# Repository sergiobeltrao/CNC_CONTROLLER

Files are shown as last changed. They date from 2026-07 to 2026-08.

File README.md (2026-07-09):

# CNC PSU and Driver Board

Project under development...

CNC PSU and Driver Board. Hardware design of a modular CNC controller integrating a 400W LLC power supply with stepper and DC motor drivers.

## Main Features
- Universal AC input: 85 VAC to 265 VAC
- 400W LLC resonant power supply
- Active Power Factor Correction (PFC)
- Stepper motor drivers
- DC motor drivers
- Microcontroller
- Compatible with grblHAL firmware

## Main Components
- **PFC Controller:** [L4986A](https://www.st.com/en/power-management/l4986.html)

- **Auxiliary Power Supply:** [VIPER222L](https://www.st.com/en/power-management/viper222.html)

- **Microcontroller:** [STM32F411CEU6](https://www.st.com/en/microcontrollers-microprocessors/stm32f411ce.html)

- **Stepper Motor Driver:** [STSPIN820](https://www.st.com/en/motor-drivers/stspin820.html)

- **DC Motor Driver:** [STSPIN840](https://www.st.com/en/motor-drivers/stspin840.html)

## Development Tools
- **PCB Design:** Altium Designer
- **Firmware:** [grblHAL](https://github.com/grblHAL/STM32F4xx)

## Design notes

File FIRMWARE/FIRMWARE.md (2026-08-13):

# Flashing the Firmware

The board can be programmed using either:

- **ST-LINK**
- **UART (STM32 Bootloader)**

The firmware source code is available in the official **grblHAL** repository for STM32F411:

https://github.com/grblHAL/STM32F4xx

For convenience, this repository also includes a **precompiled binary** in this directory, ready to be flashed to the board.

## ST-LINK Programming

1. Download and install **STM32CubeProgrammer** from the STMicroelectronics website:

   https://www.st.com/en/development-tools/stm32cubeprog.html

2. Connect the following signals to connector **P201**:
   - **SWDIO**
   - **SWCLK**
   - **GND**
   - **3.3V**

3. Open **STM32CubeProgrammer**, select **ST-LINK** as the connection interface, configure the connection parameters as shown below, and click **Connect**.

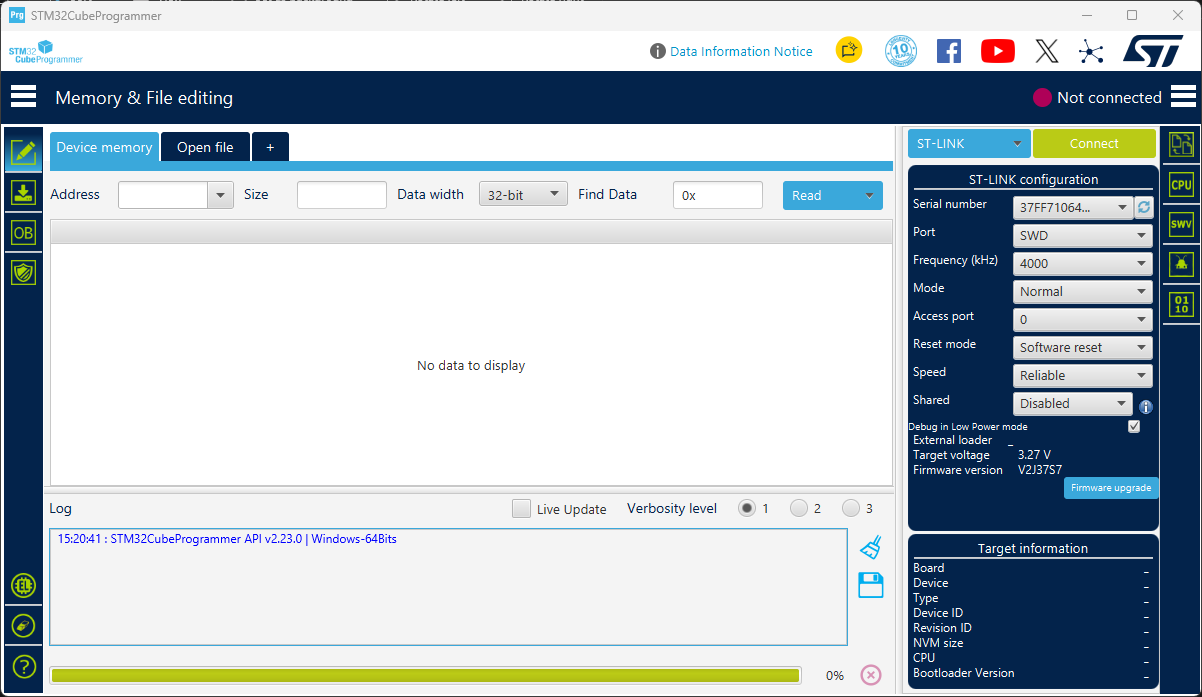
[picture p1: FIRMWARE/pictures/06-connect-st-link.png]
   

4. If the connection is successful, the microcontroller information will be displayed in the lower-right corner of the window.

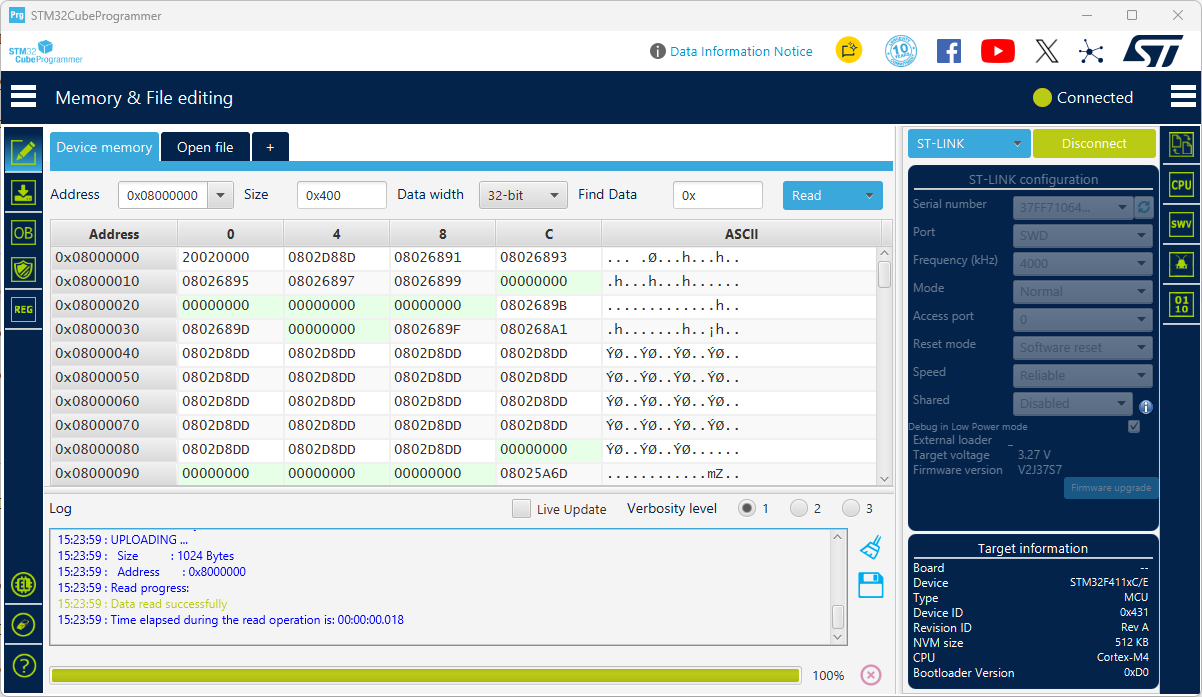
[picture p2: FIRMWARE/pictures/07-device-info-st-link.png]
   

5. In the left panel, select **Erasing & Programming**. Then select the firmware **.bin** file and click **Start Programming**.

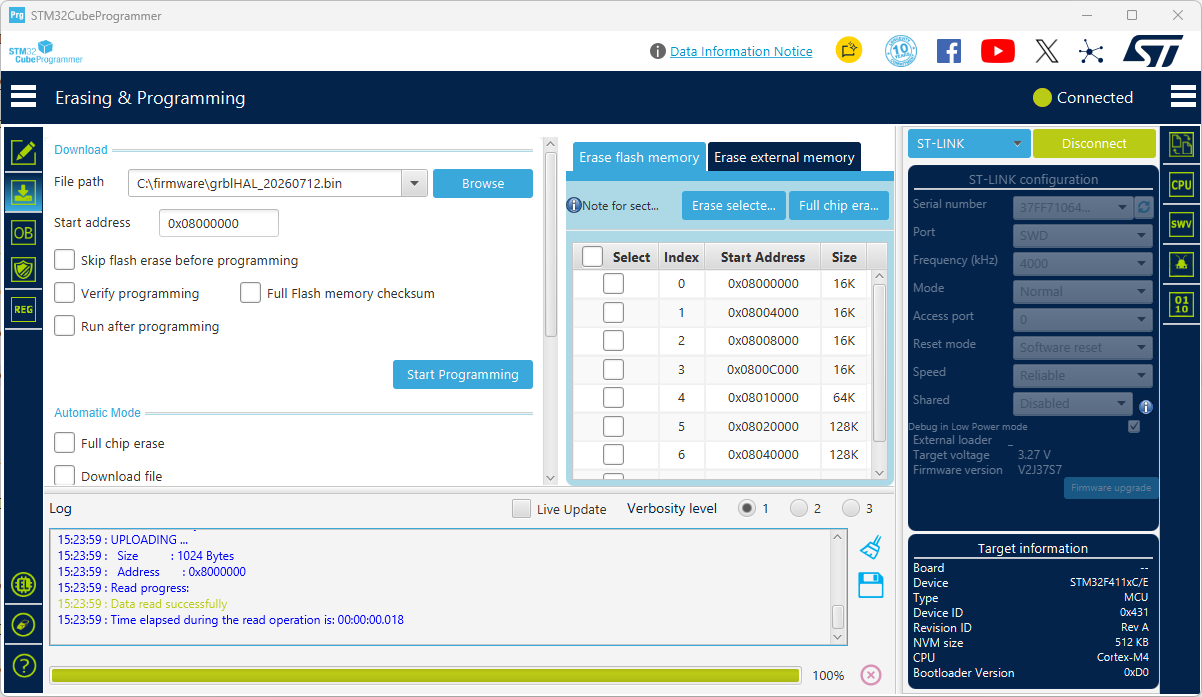
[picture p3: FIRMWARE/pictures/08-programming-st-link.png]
Preparing to program
   

6. Wait for the programming process to complete. When the **"File download complete"** message appears, the firmware has been successfully programmed.

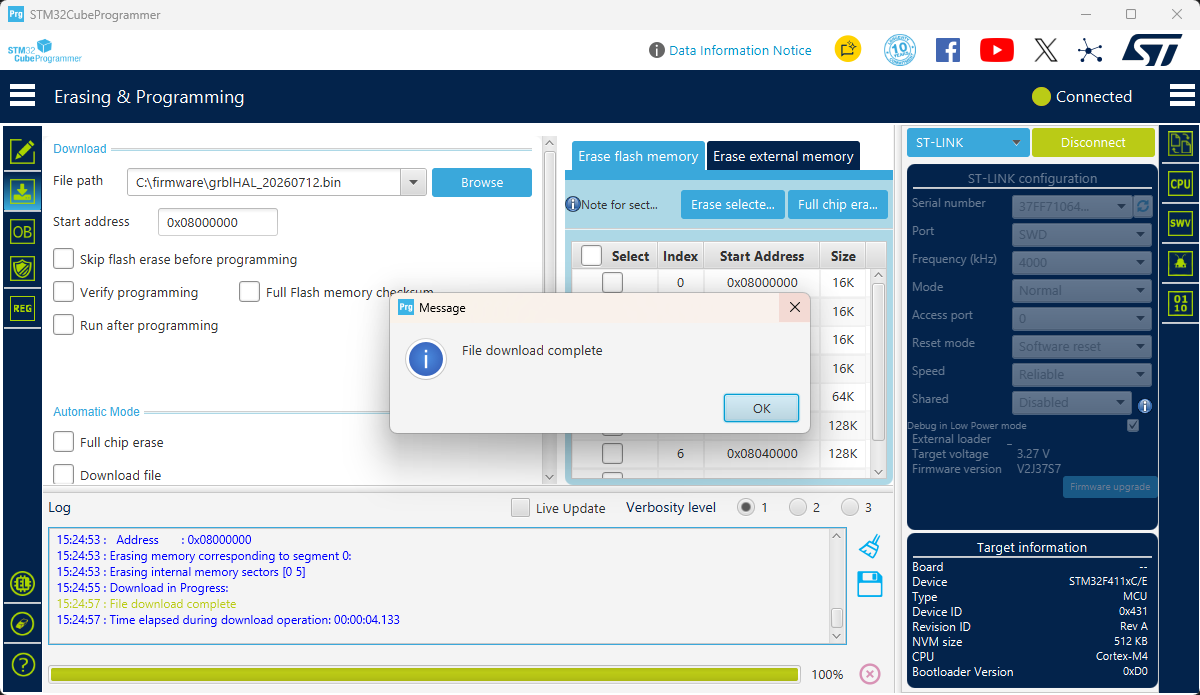
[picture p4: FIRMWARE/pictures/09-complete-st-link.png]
   

You can now disconnect the ST-LINK programmer and reset or power cycle the board to start the new firmware.

## UART Programming (Bootloader Mode)

1. Download and install **STM32CubeProgrammer** from the STMicroelectronics website:

   https://www.st.com/en/development-tools/stm32cubeprog.html

2. Connect the following signals to connector **P200**:
   - **TX**
   - **RX**
   - **VCC**
   - **GND**

3. Put the microcontroller into **Bootloader Mode**:
   1. Press and hold the **NRST** button.
   2. Press and hold the **BOOT** button.
   3. Release the **NRST** button.
   4. Release the **BOOT** button.

4. Open **STM32CubeProgrammer**, configure the connection as shown below, and click **Connect**.

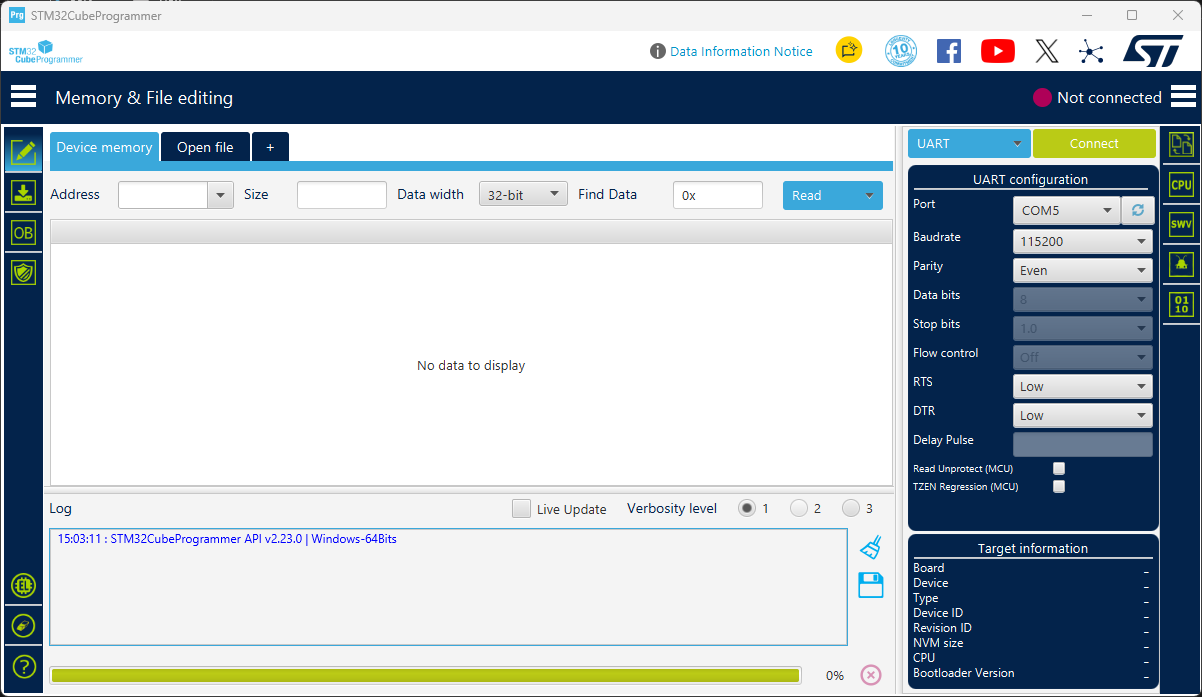
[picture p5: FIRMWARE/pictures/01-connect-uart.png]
   

5. If the connection is successful, the microcontroller information will be displayed in the lower-right corner of the window.

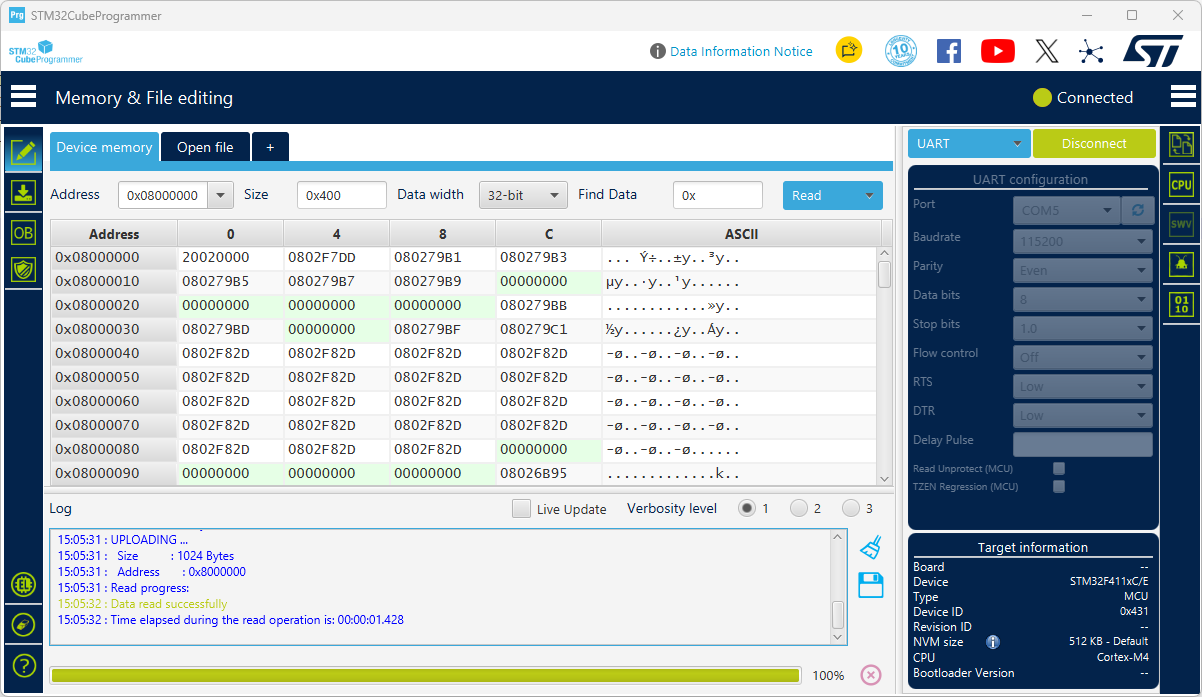
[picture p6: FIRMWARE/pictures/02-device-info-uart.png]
   

6. In the left panel, select the **Erasing & Programming** tab. Browse for the firmware **.bin** file and click **Start Programming**.

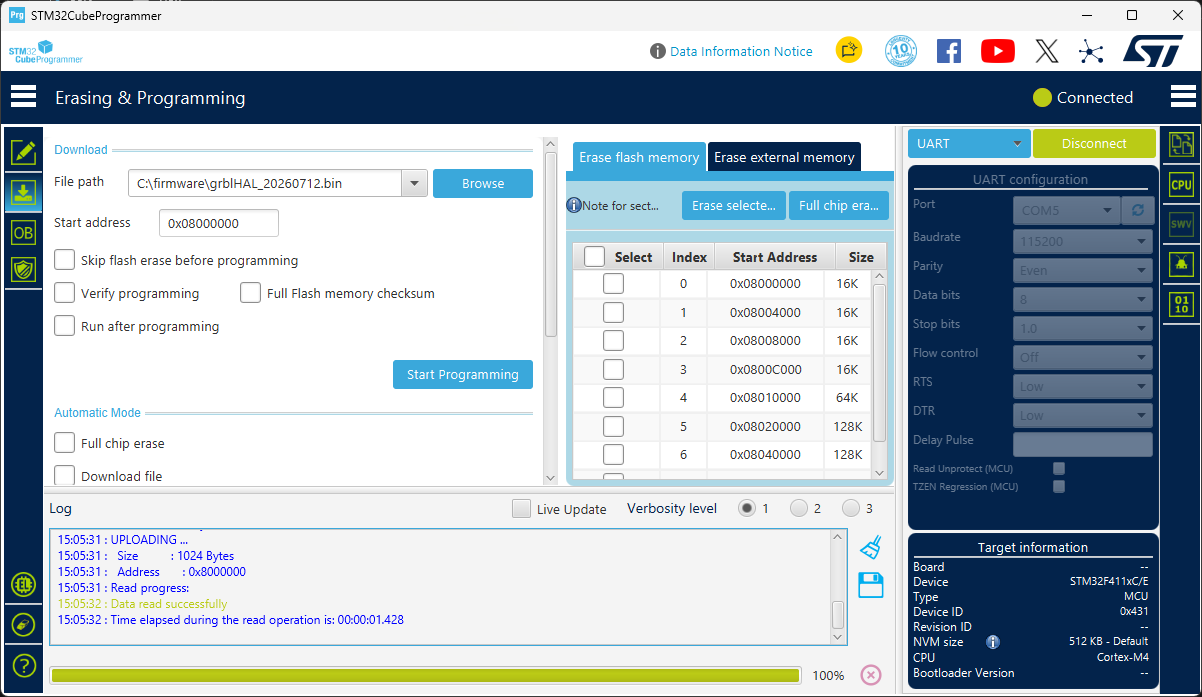
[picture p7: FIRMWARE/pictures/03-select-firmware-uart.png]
   

7. Wait for the programming process to complete.

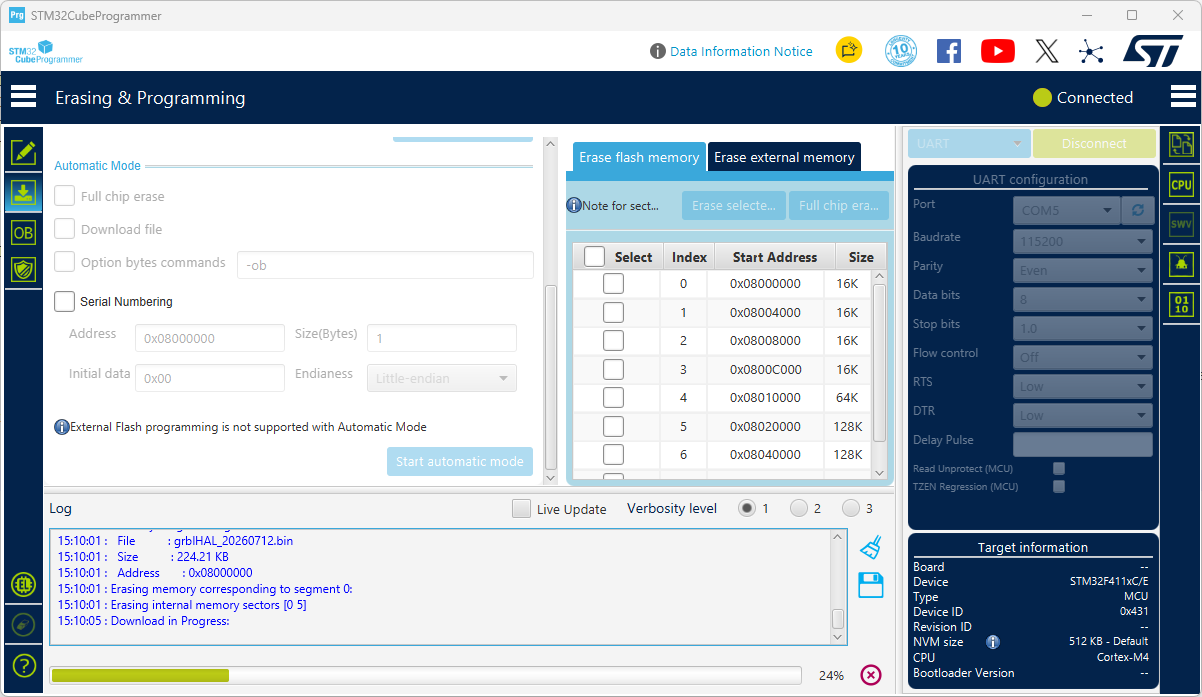
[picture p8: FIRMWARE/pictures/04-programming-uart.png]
Programming in progress
   

8. When the message **"File download complete"** appears, the firmware has been successfully programmed.

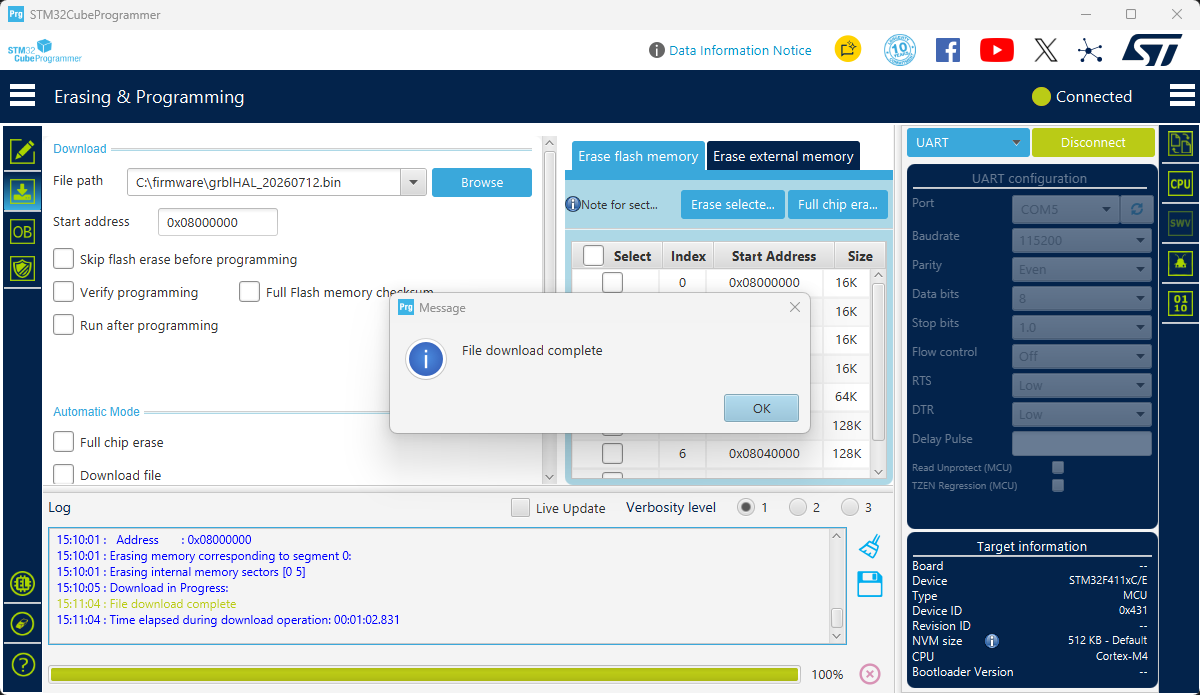
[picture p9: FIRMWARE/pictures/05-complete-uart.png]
   

You can now disconnect the board from **STM32CubeProgrammer** and reset or power-cycle the microcontroller to start the new firmware.

# grblHAL Configuration

After flashing the firmware, configure the following parameters:

| Parameter | Value | Description |
|---|:-----:|---|
| `$5` | `0` | Sets the limit switches as **active-high**. |
| `$21` | `1` | Enables the physical limit switches. When triggered, grblHAL enters the alarm state and immediately stops all motion. |
| `$6` | `0` | Sets the **probe** input as **active-high**. |

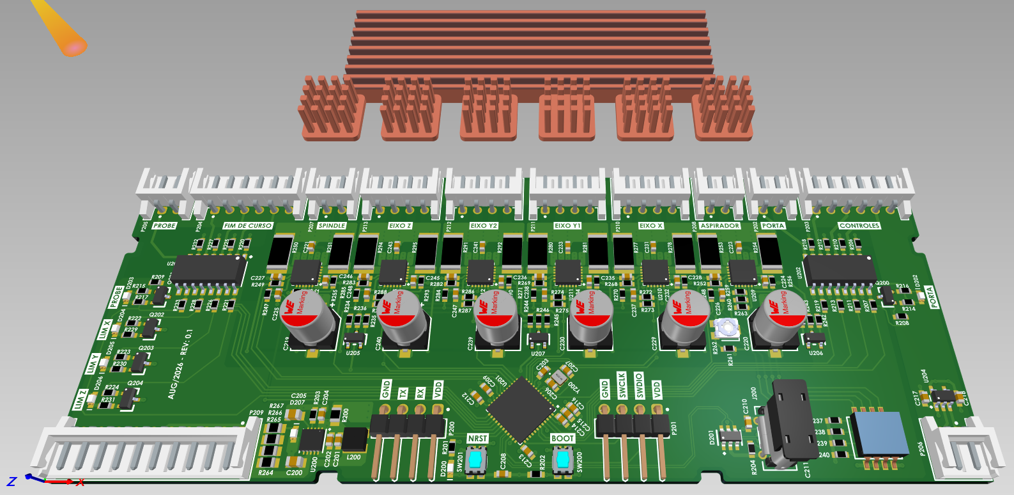
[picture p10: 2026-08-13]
PRODUCTION_FILES/REV_0_1/DRIVER_REV_0_1.png

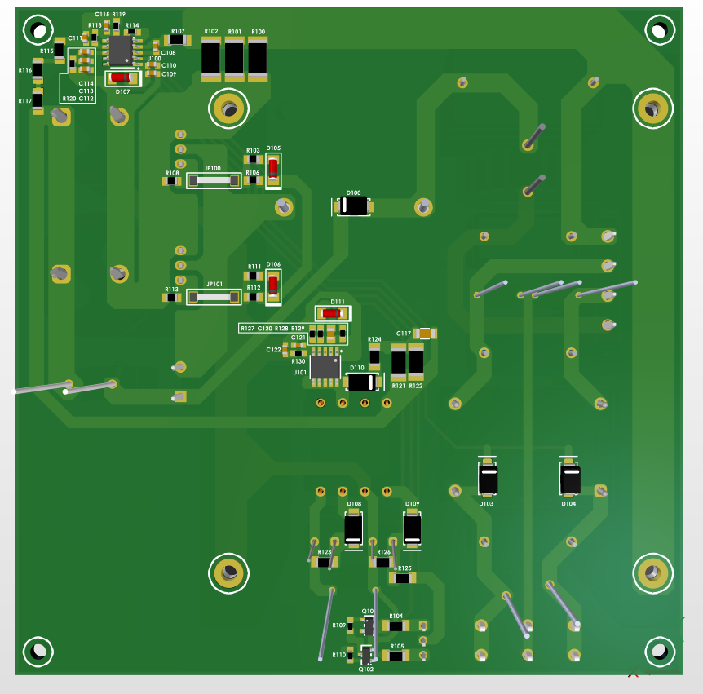
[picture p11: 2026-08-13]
PRODUCTION_FILES/REV_0_1/PSU_REV_0_1_BOTTOM.png

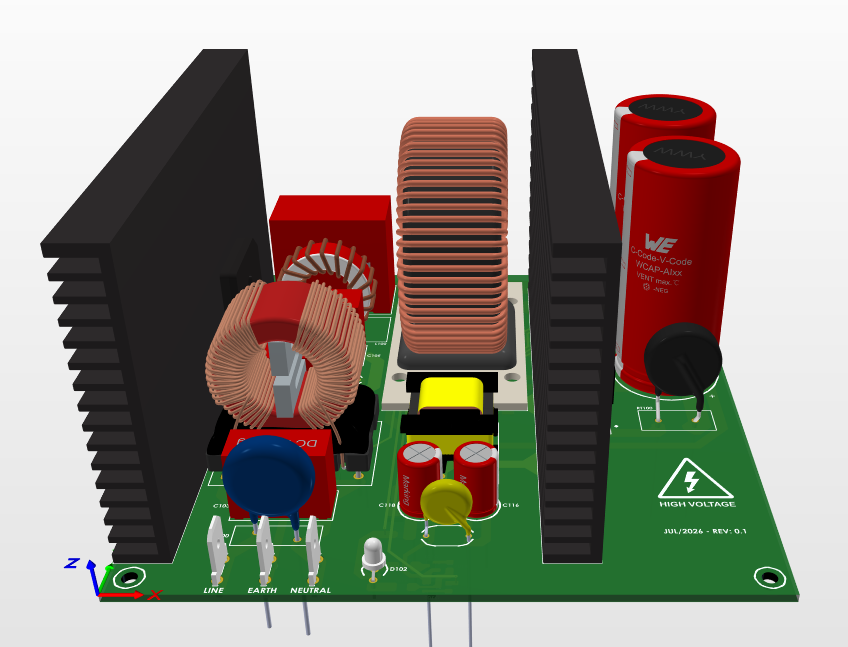
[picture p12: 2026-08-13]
PRODUCTION_FILES/REV_0_1/PSU_REV_0_1_TOP.png

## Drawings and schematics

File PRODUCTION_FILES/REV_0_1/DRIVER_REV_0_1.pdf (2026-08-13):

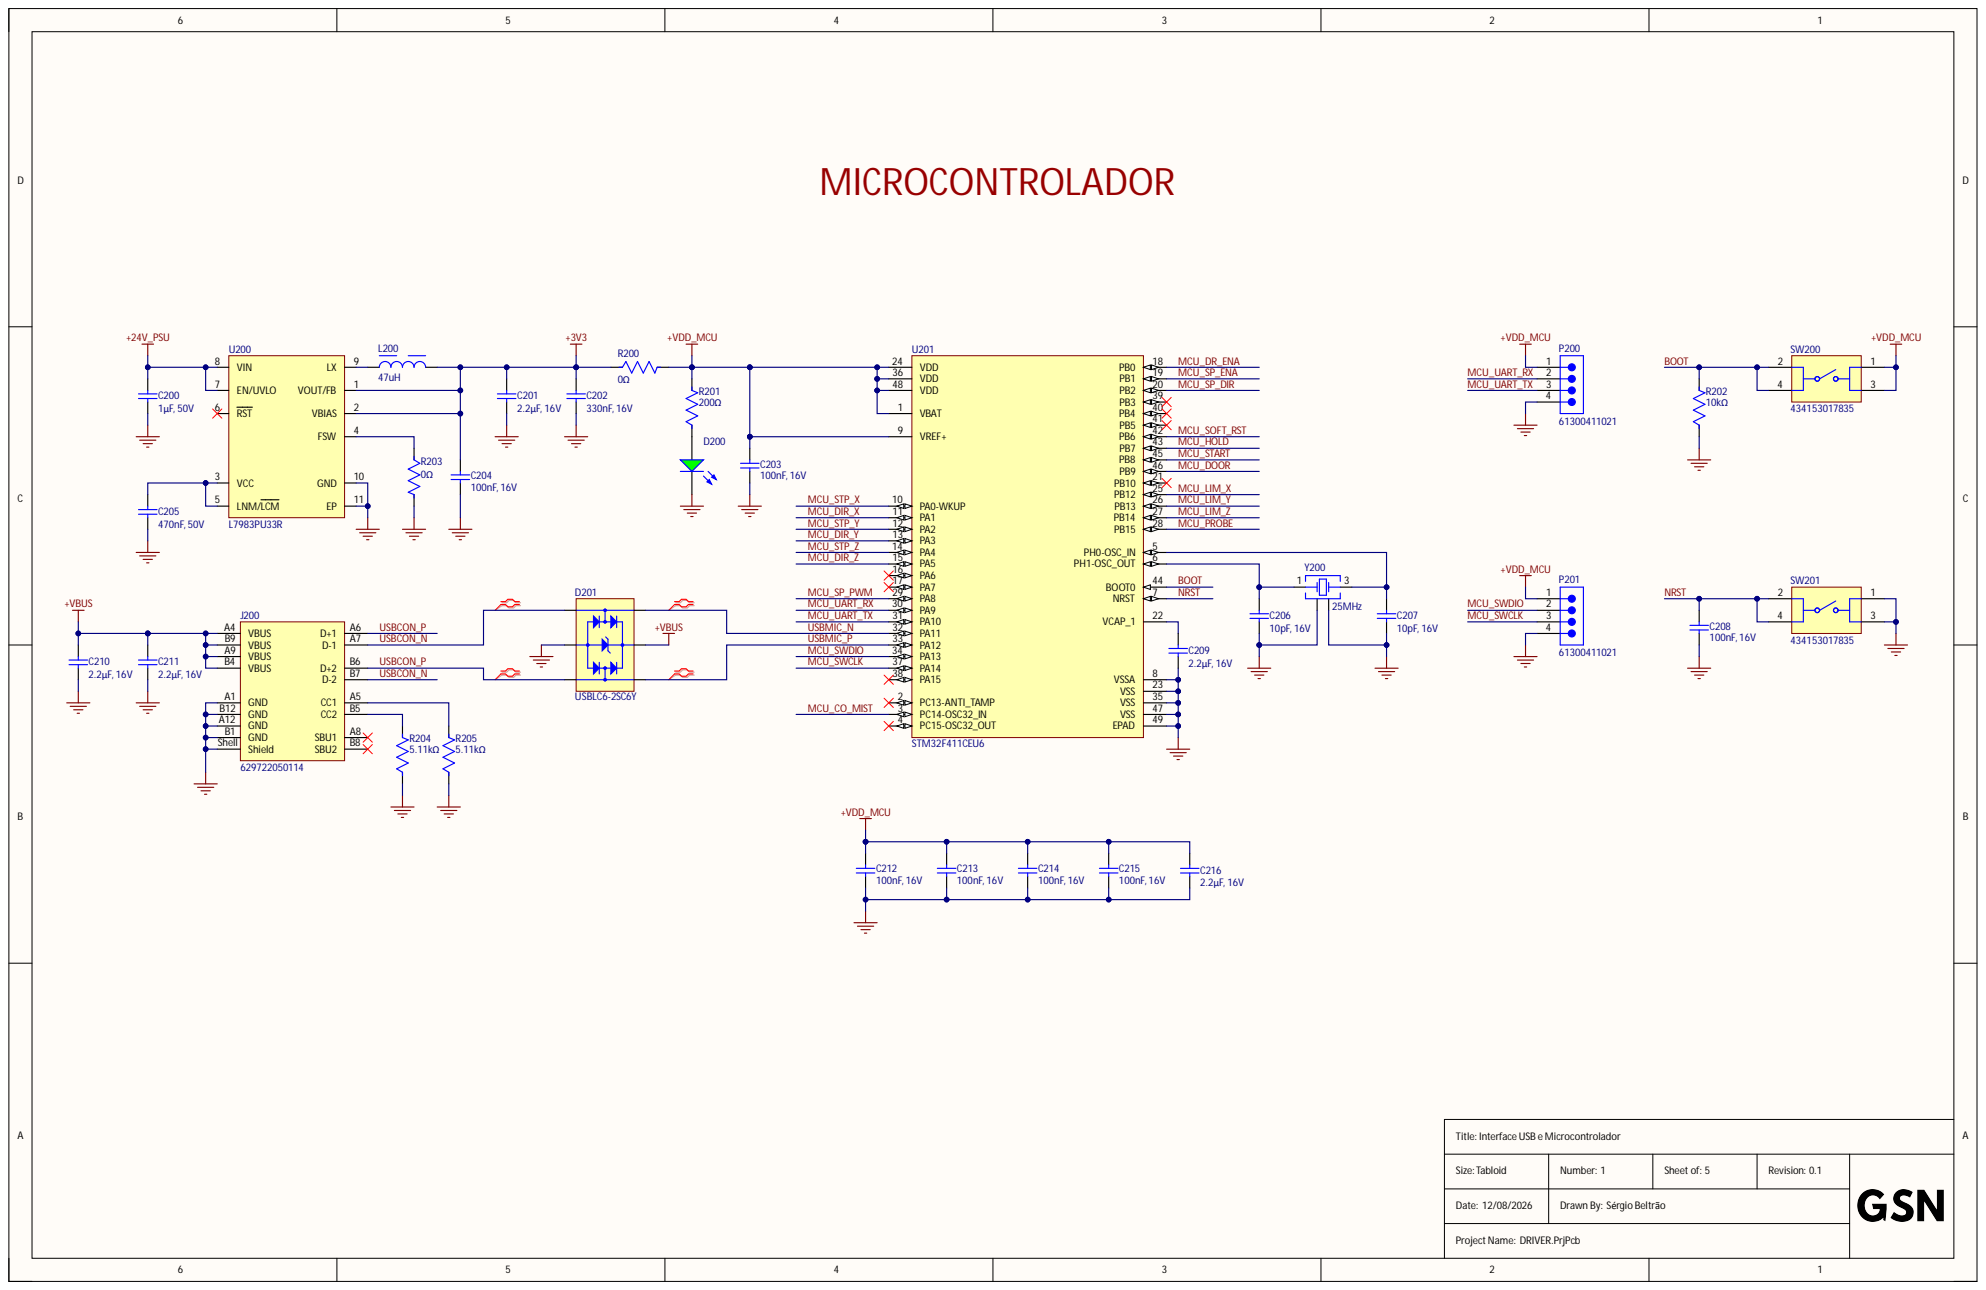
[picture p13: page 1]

48 | 20 MCU_SP_ D I R

44 7 | BO OT NRST

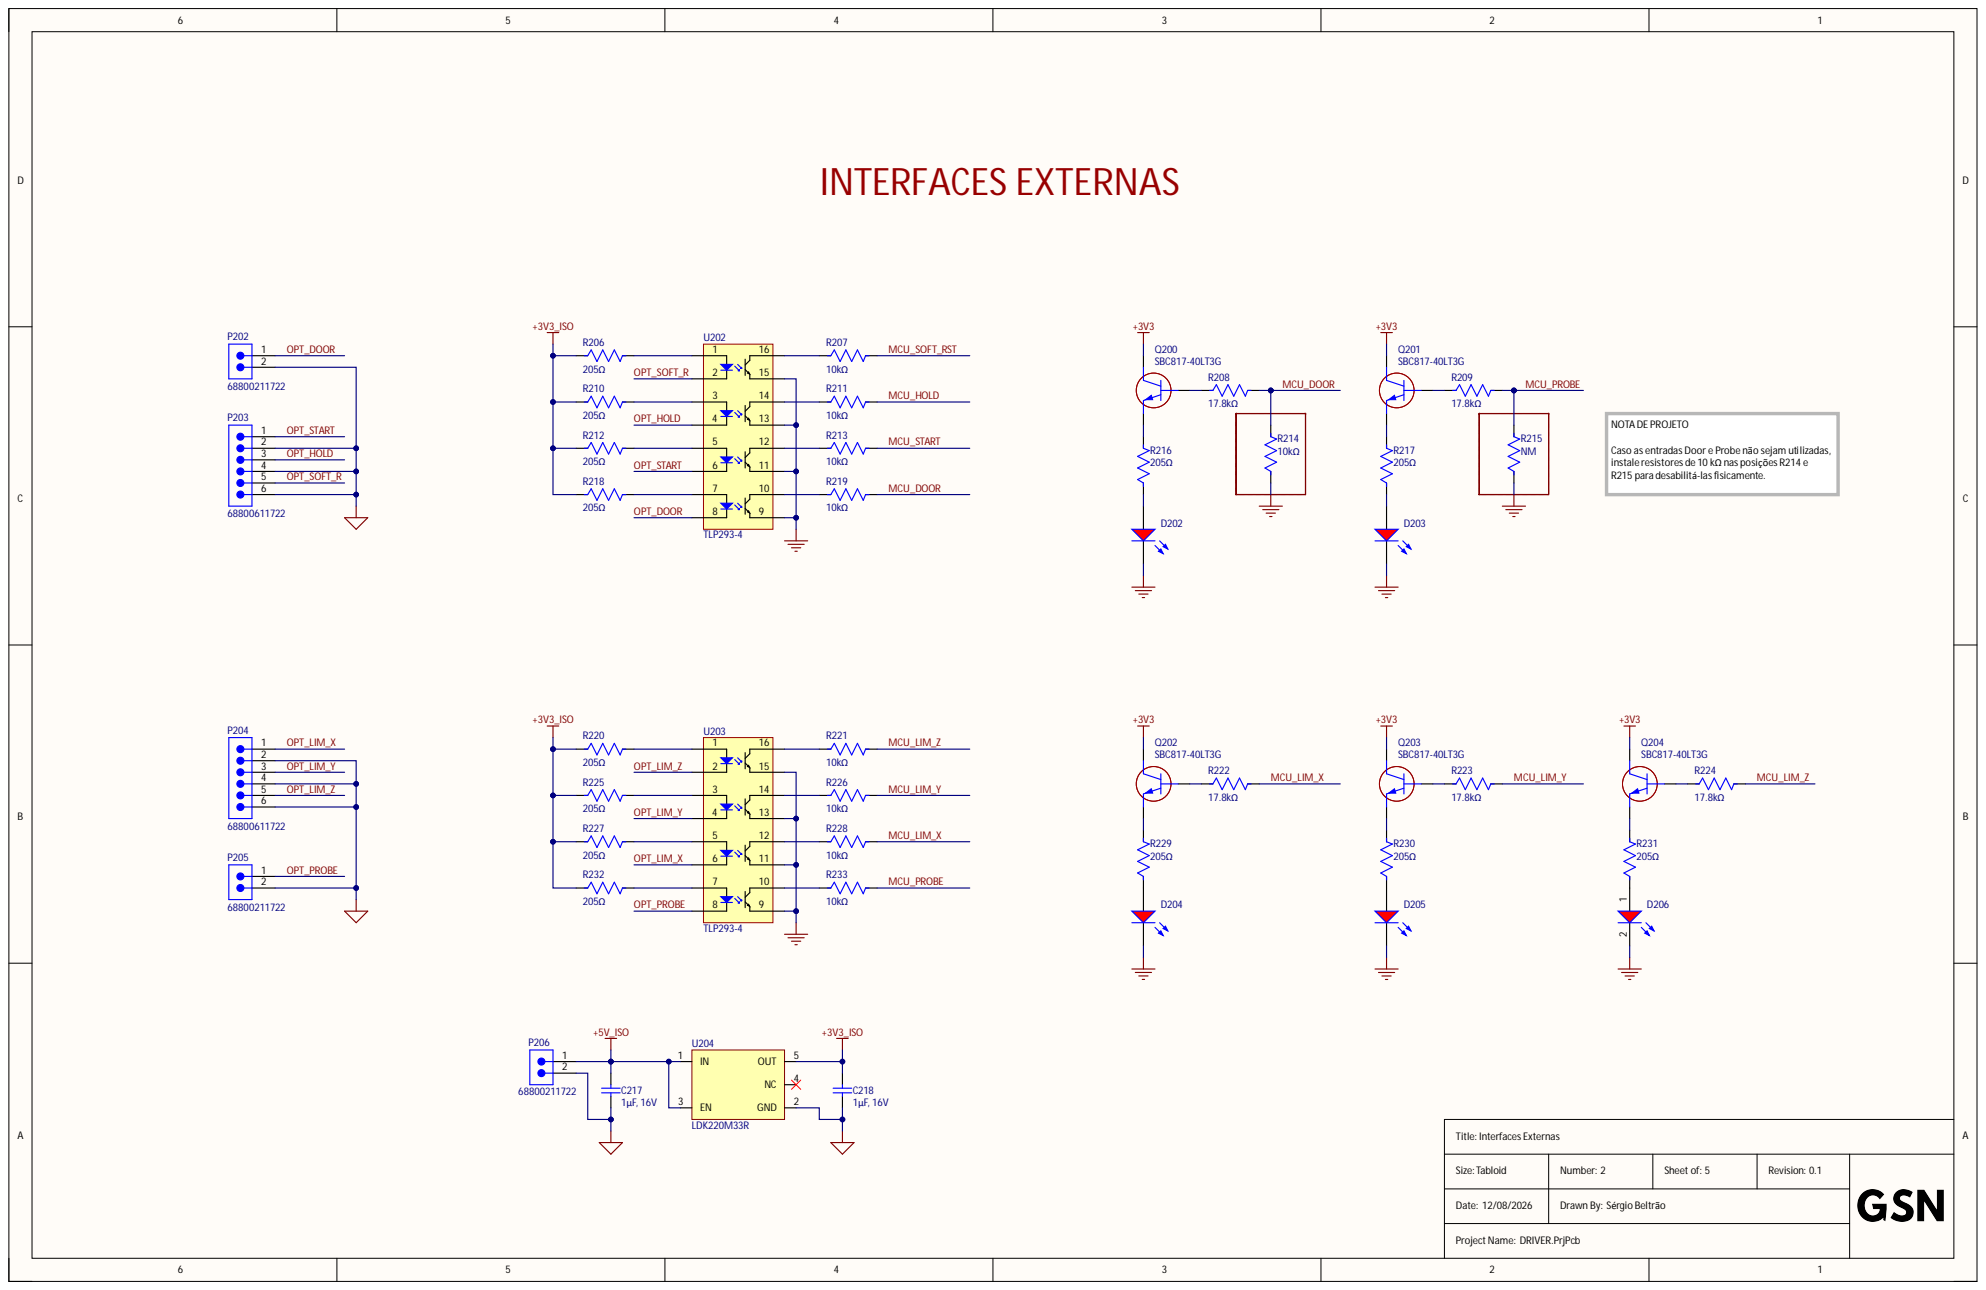
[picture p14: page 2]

OPT_ LIM_Y

OPT_ LIM_Z

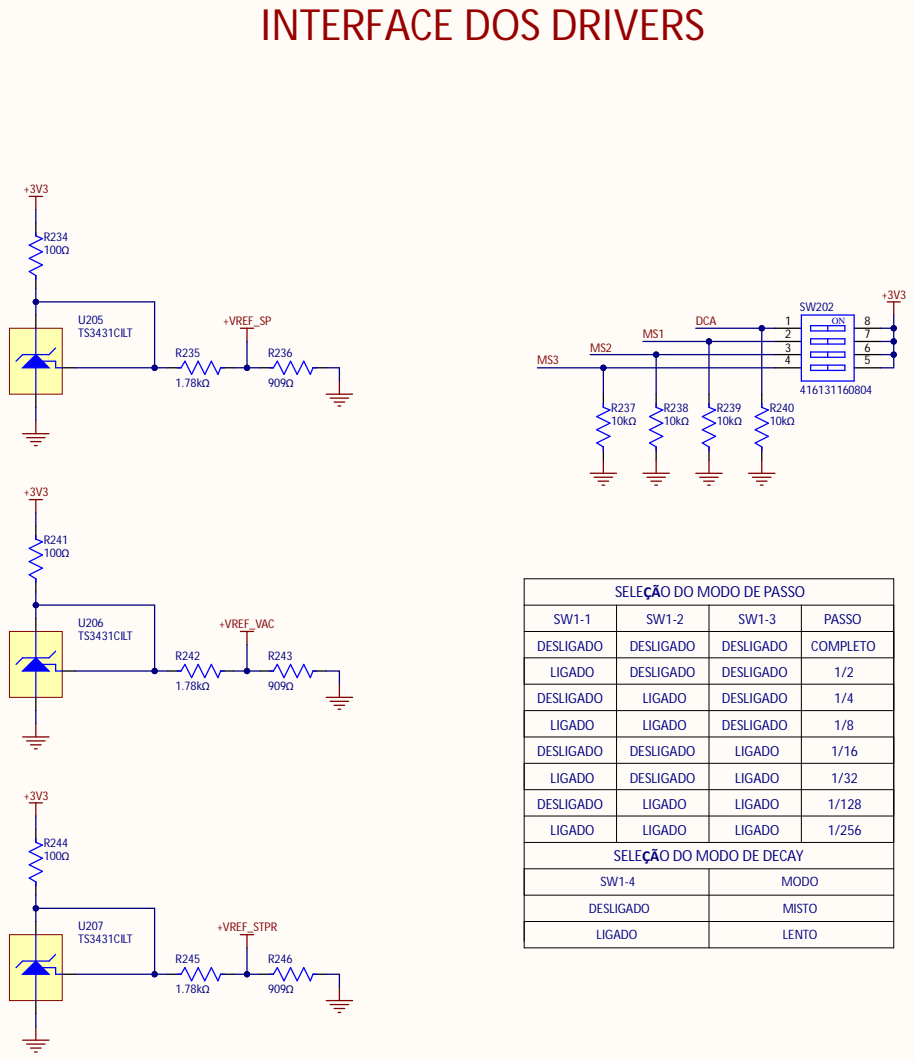
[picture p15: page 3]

SELEÇÃO DO MODO DE PASSO

SW1-1 | SW1-2 | SW1-3 | PASSO

DESLIGADO | DESLIGADO | DESLIGADO | COMPLETO

LIGADO | DESLIGADO | DESLIGADO | 1/2

DESLIGADO | LIGADO | DESLIGADO | 1/4

LIGADO | LIGADO | DESLIGADO | 1/8

DESLIGADO | DESLIGADO | LIGADO | 1/16

LIGADO | DESLIGADO | LIGADO | 1/32

DESLIGADO | LIGADO | LIGADO | 1/128

LIGADO | LIGADO | LIGADO | 1/256

SELEÇÃO DO MODO DE DECAY

SW1-4 | MODO

DESLIGADO | MISTO

LIGADO | LENTO

VREF e Seleção de Micropassos

Drawn By: Sérgio Beltrão

Project Name: DRIVER.PrjPcb

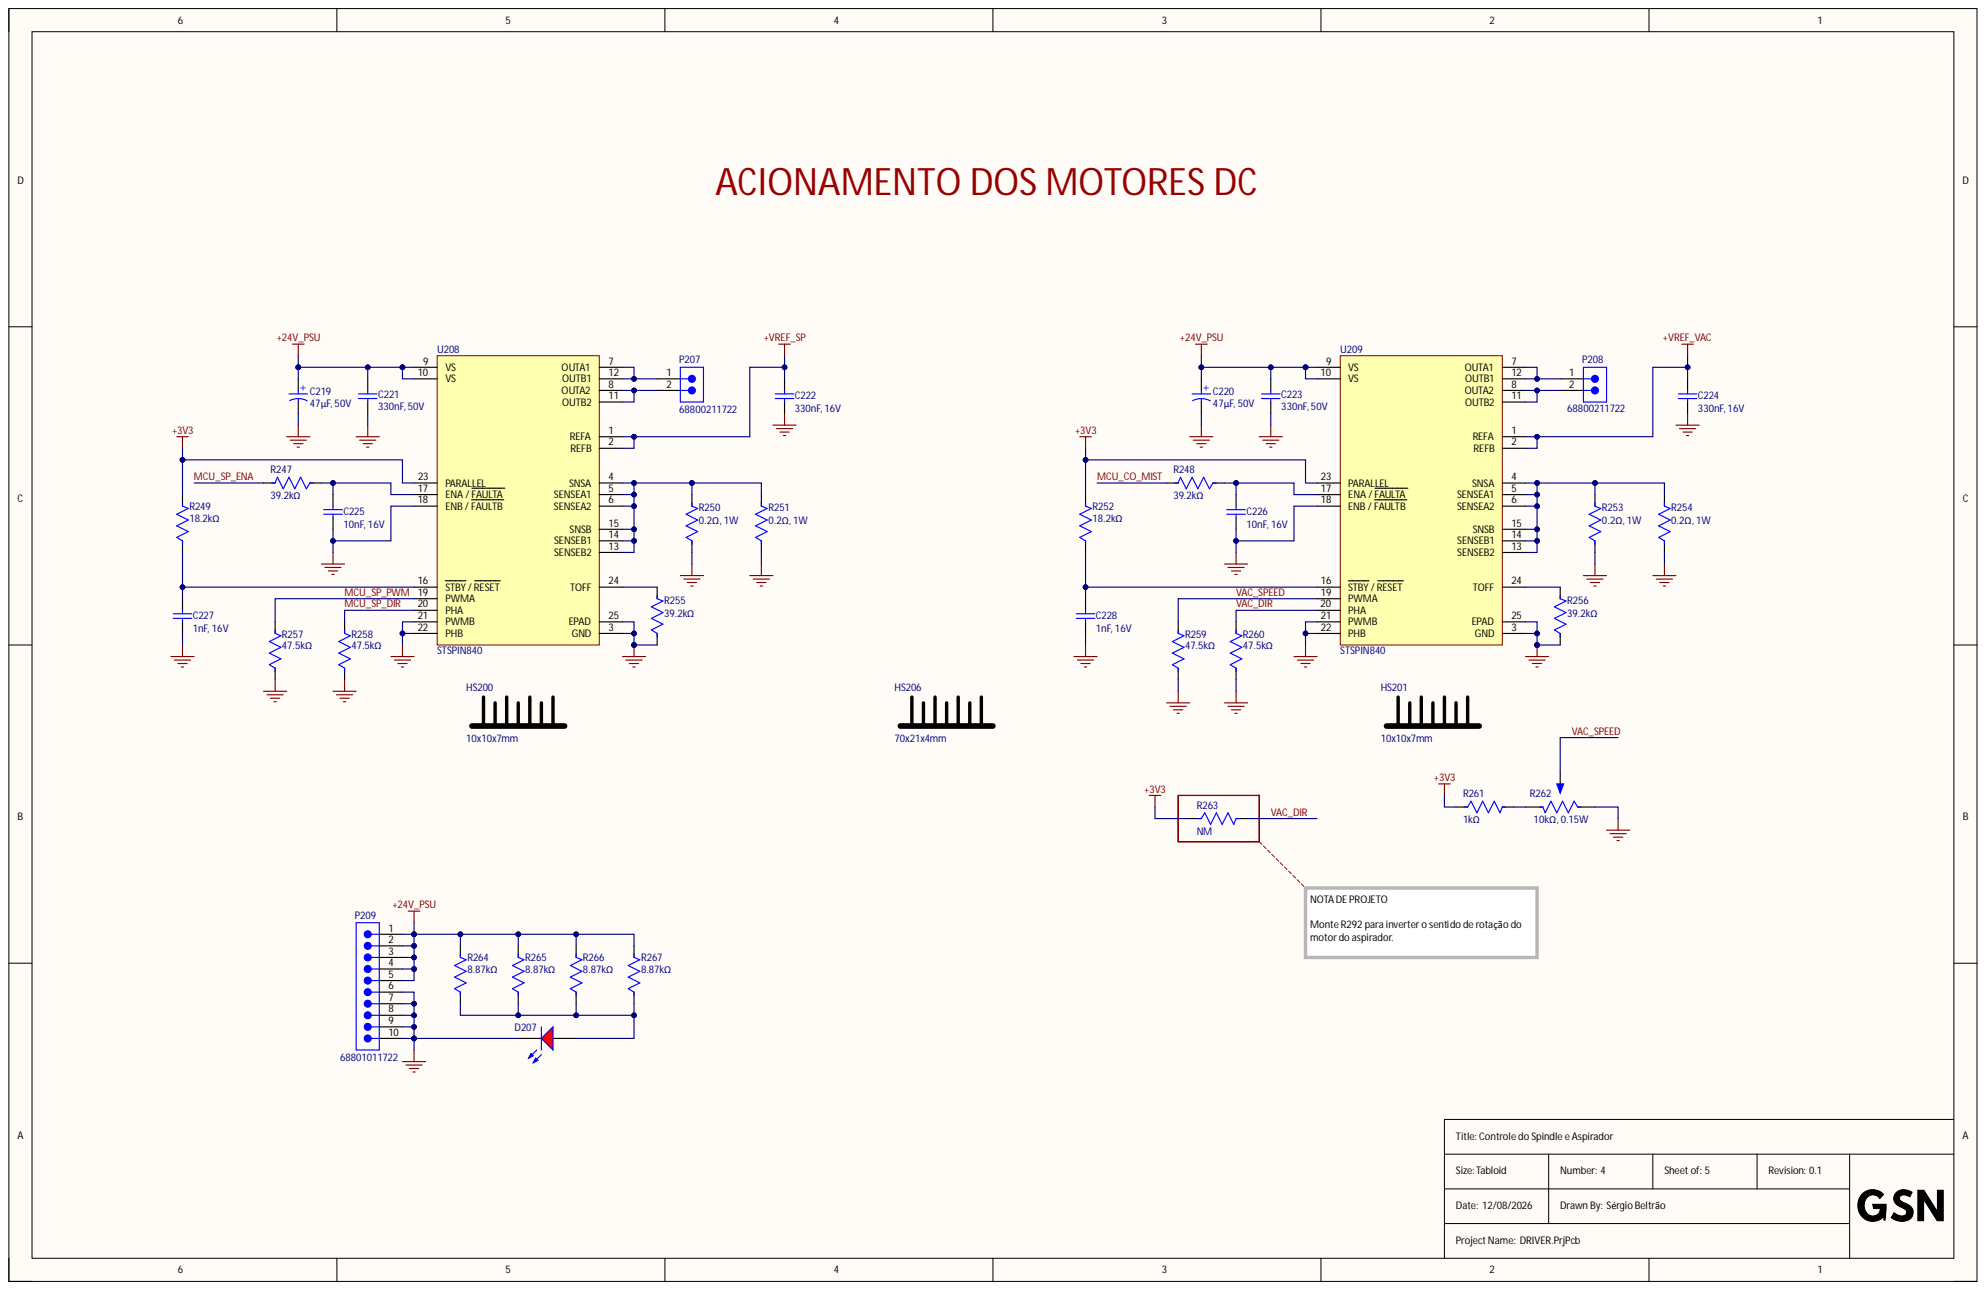
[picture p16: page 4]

ACIONAMENTO DOS MOTORES DC

Monte R292 para inverter o sentido de rotação do
motor do aspirador.

Controle do Spindle e Aspirador

Drawn By: Sérgio Beltrão

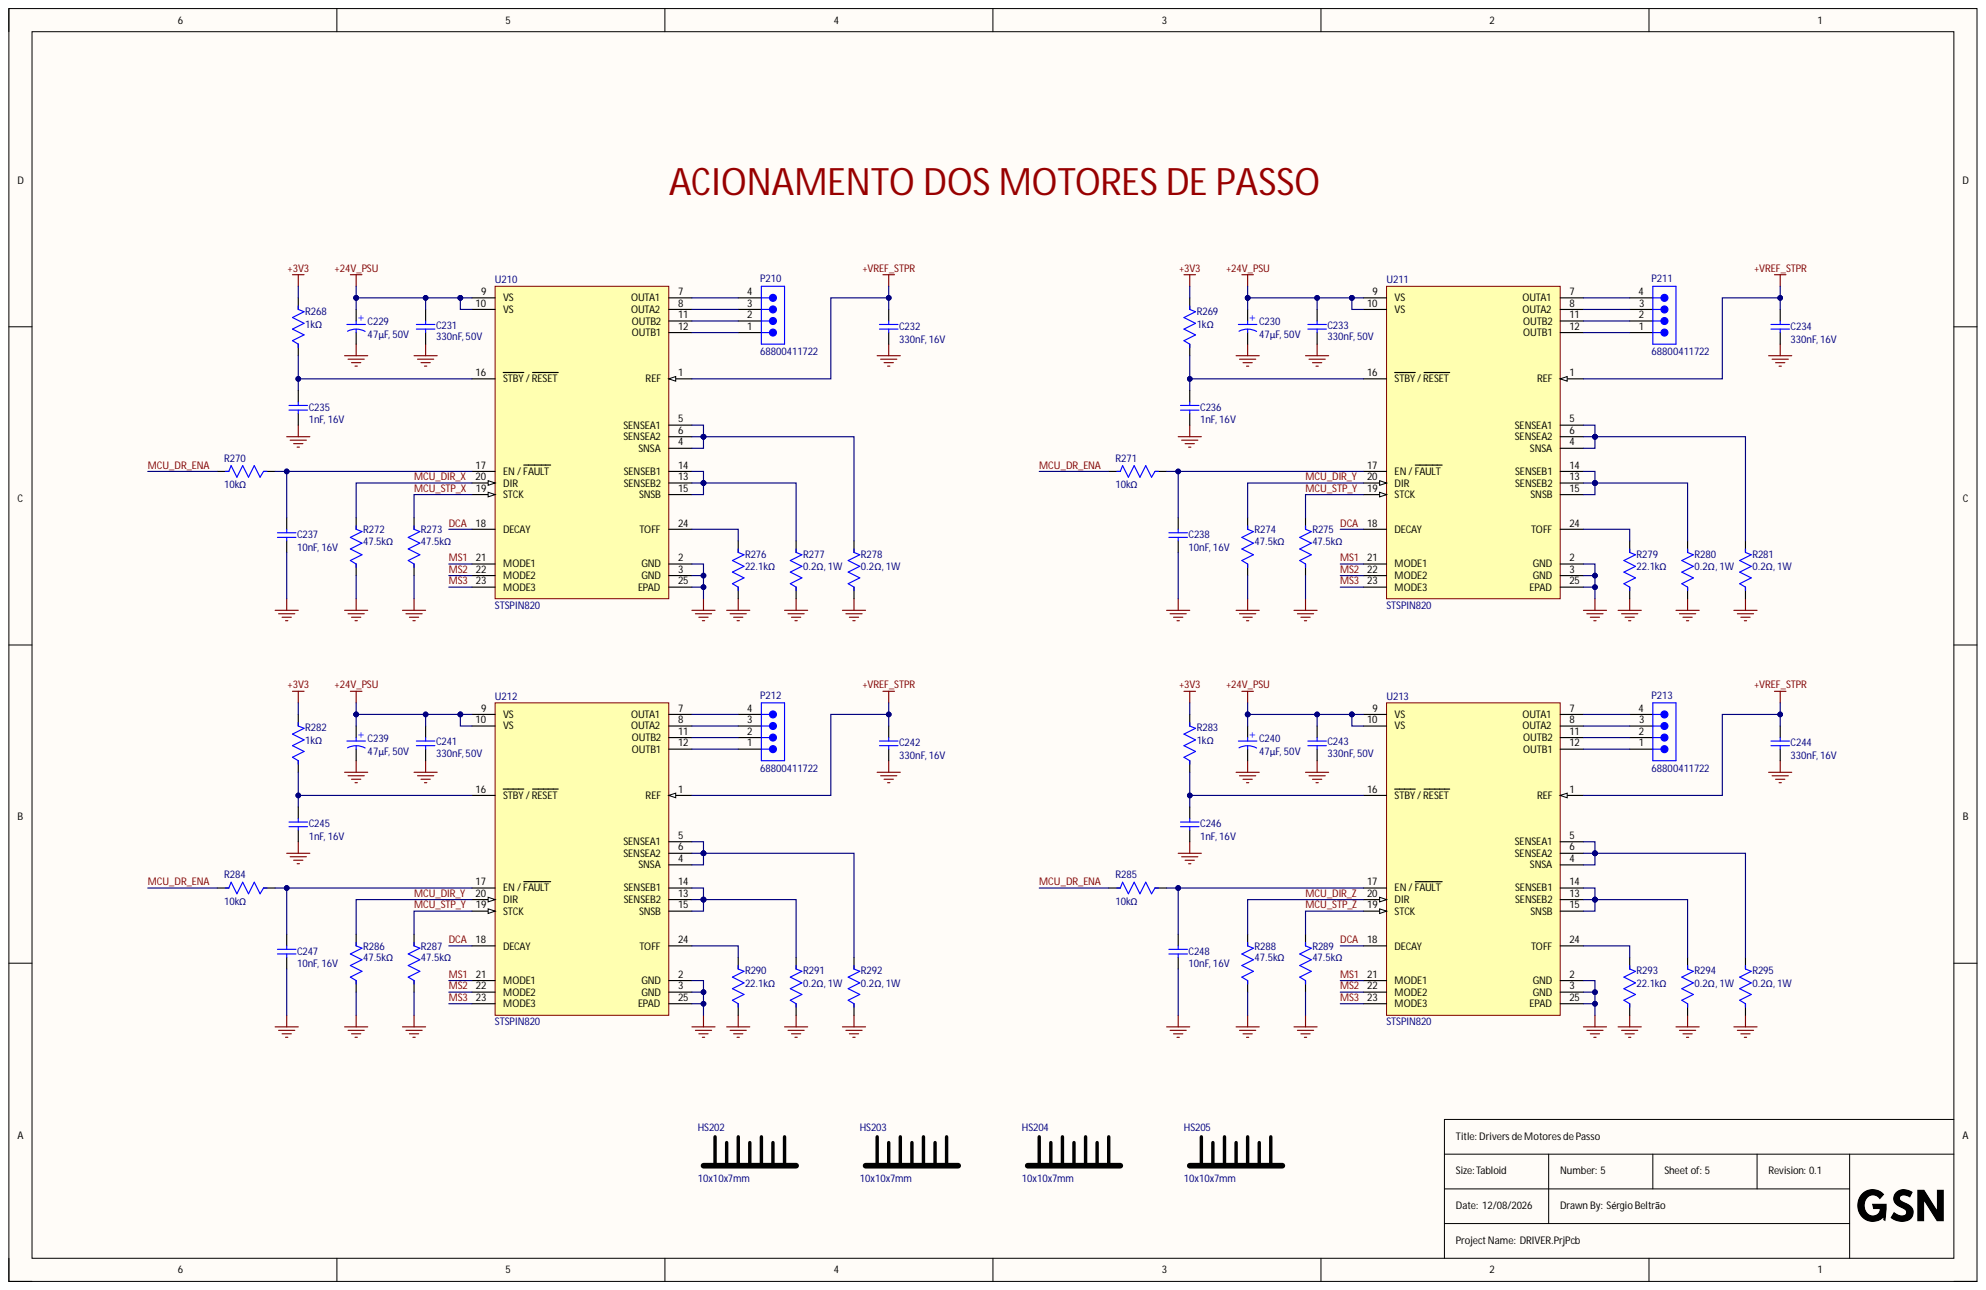
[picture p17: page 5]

ACIONAMENTO DOS MOTORES DE PASSO

Drivers de Motores de Passo

Drawn By: Sérgio Beltrão

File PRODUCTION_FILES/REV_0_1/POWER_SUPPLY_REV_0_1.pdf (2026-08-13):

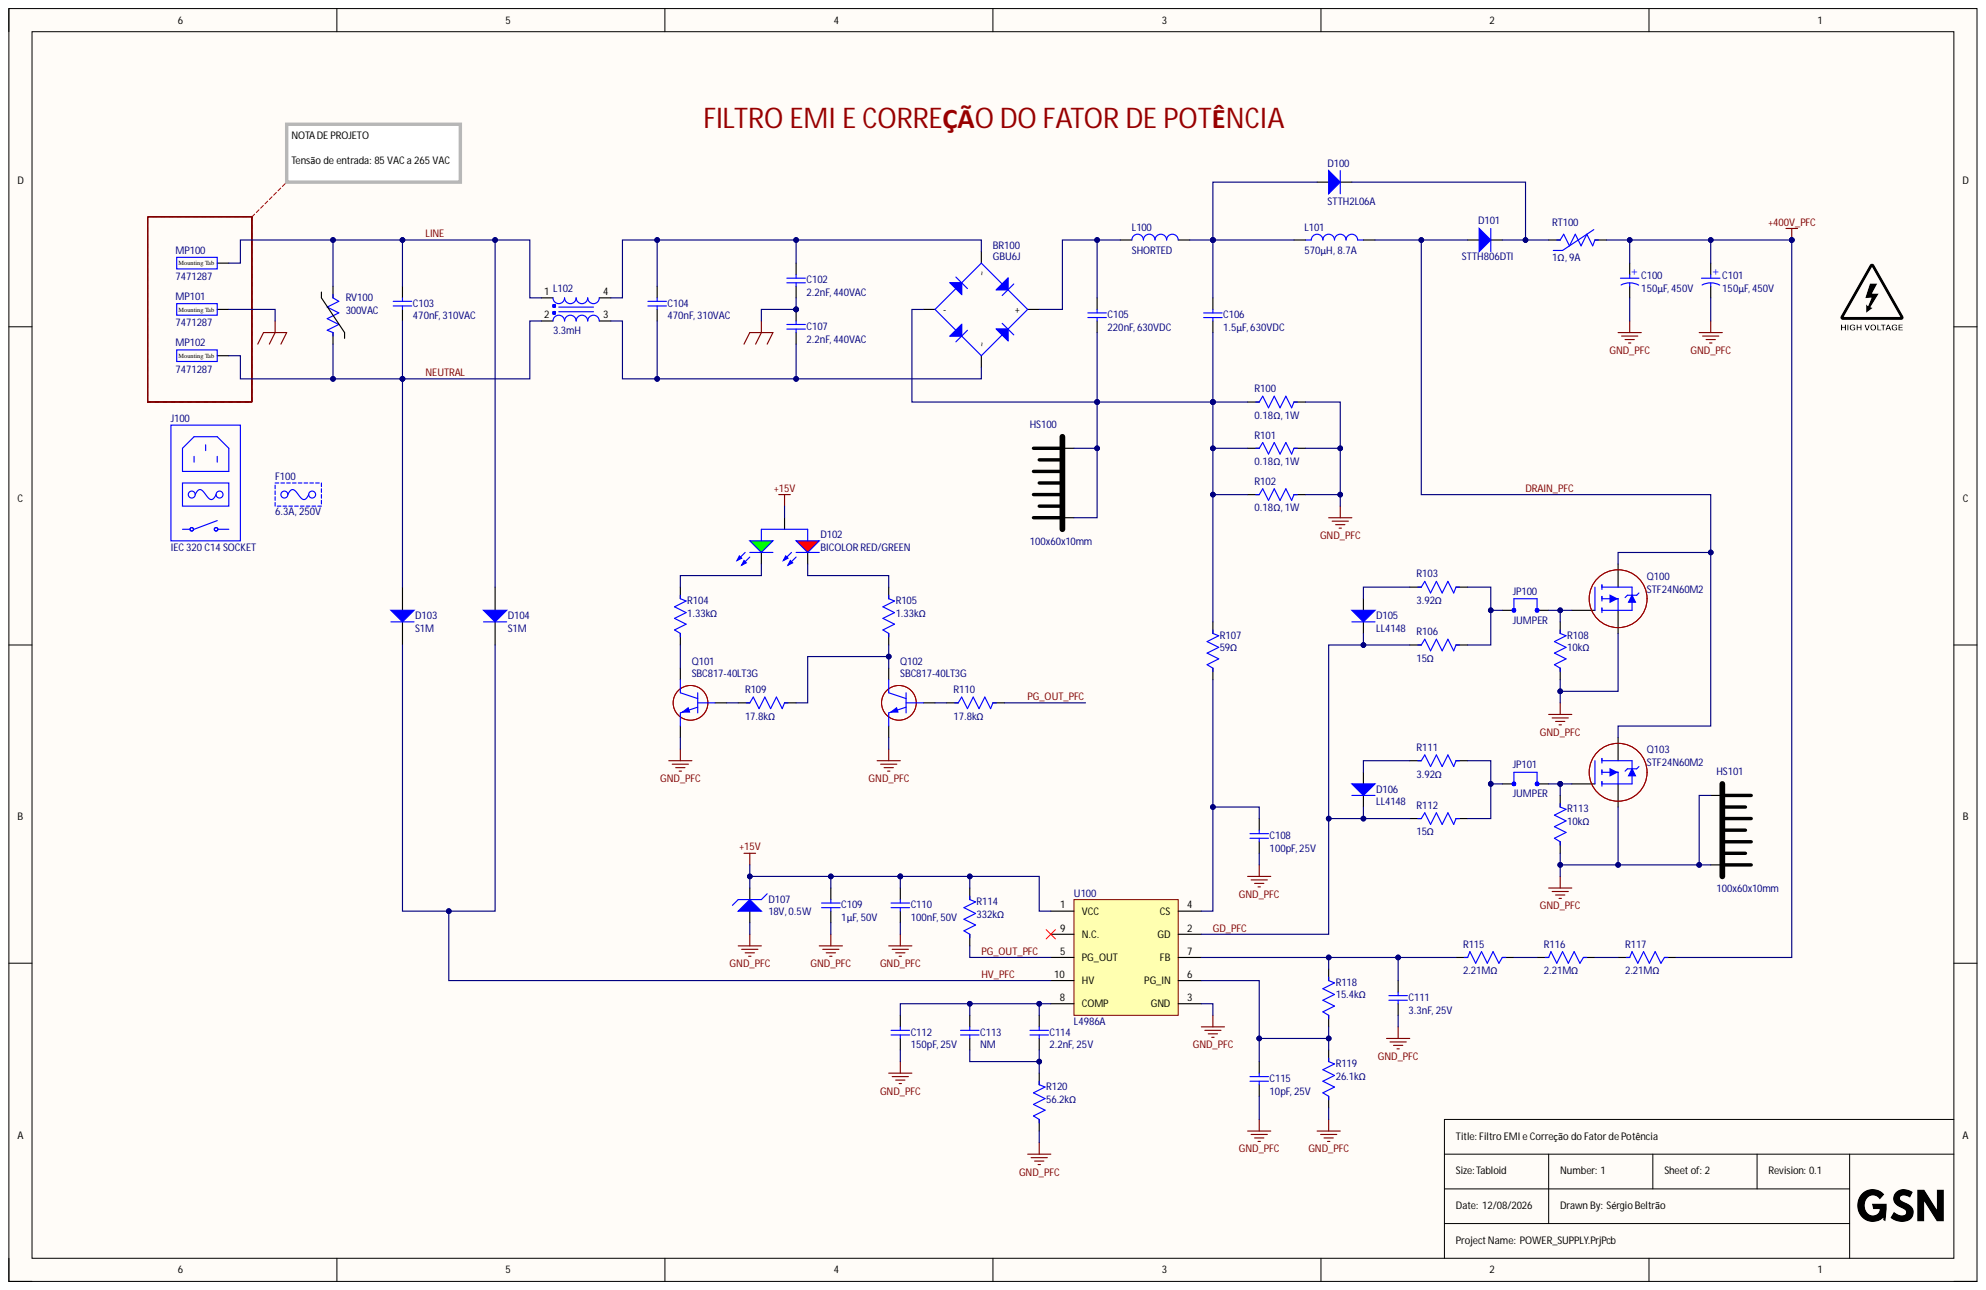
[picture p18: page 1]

FILTRO EMI E CORREÇÃO DO FATOR DE POTÊNCIA

Tensão de entrada: 85 VAC a 265 VAC

C106 1.5µF, 630VDC | DRAIN_PFC

GND_PFC

Filtro EMI e Correção do Fator de Potência

Drawn By: Sérgio Beltrão

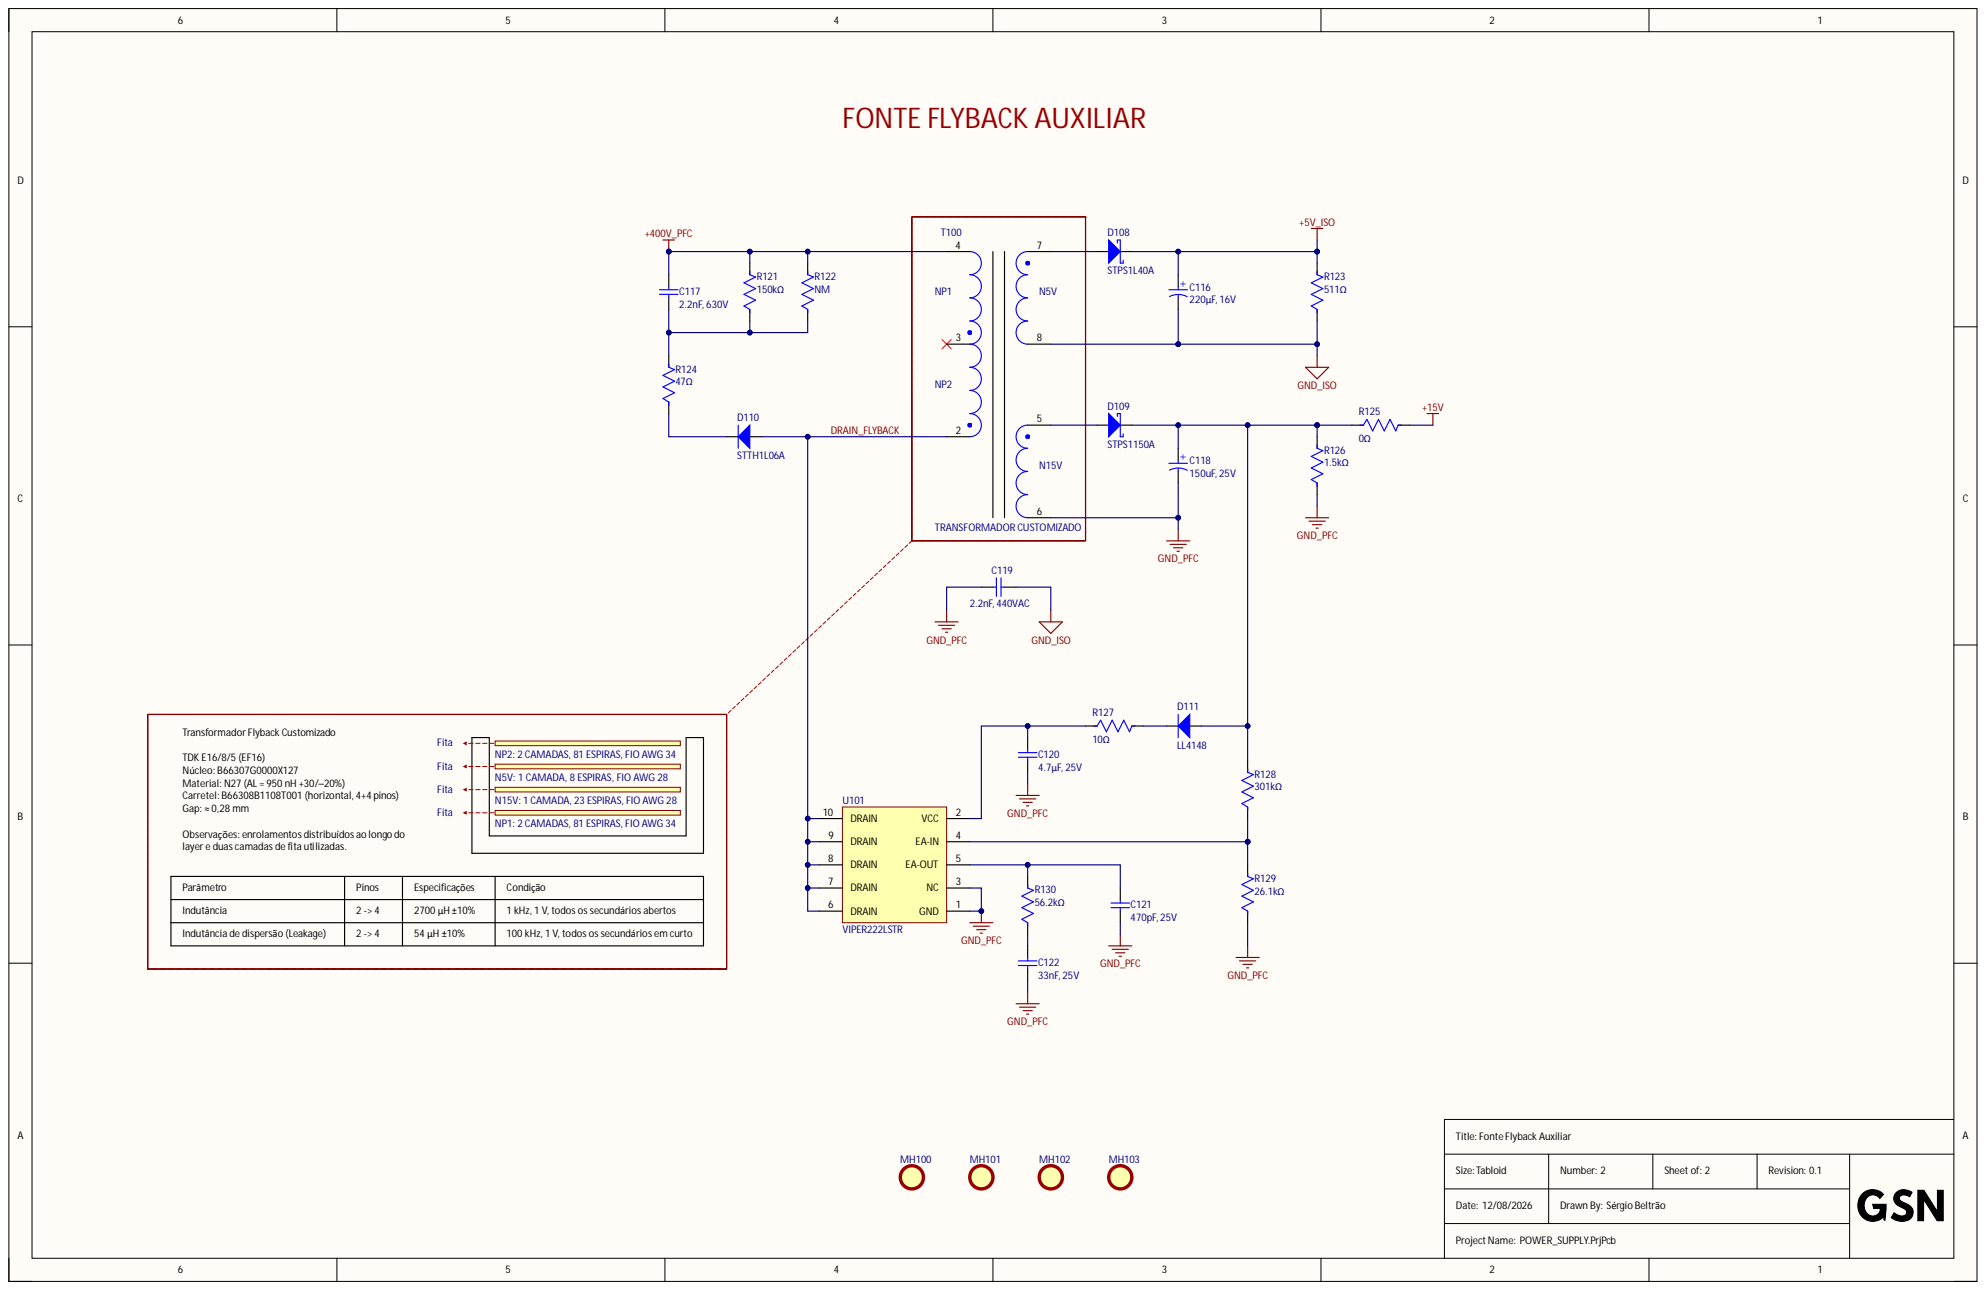
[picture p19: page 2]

NP2: 2 CAMADAS, 81 ESPIRAS, FIO AWG 34

N5V: 1 CAMADA, 8 ESPIRAS, FIO AWG 28

N15V: 1 CAMADA, 23 ESPIRAS, FIO AWG 28

NP1: 2 CAMADAS, 81 ESPIRAS, FIO AWG 34

Observações: enrolamentos distribuídos ao longo do
layer e duas camadas de fita utilizadas.

Parâmetro | Pinos | Especificações | Condição

Indutância | 2 -> 4 | 2700 µH ±10% | 1 kHz, 1 V, todos os secundários abertos

Indutância de dispersão (Leakage) | 2 -> 4 | 54 µH ±10% | 100 kHz, 1 V, todos os secundários em curto

Drawn By: Sérgio Beltrão

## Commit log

2026-07-09 09 jul 2026
    [1_PAGINA_INICIAL.SchDoc, 1_PFC.SchDoc, 2_ALIMENTACAO_24V_5V_3V3.SchDoc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]
2026-07-10 10 jul 2026
    [1_PAGINA_INICIAL.SchDoc, 2_ALIMENTACAO_24V_5V_3V3.SchDoc, 4_DRV_MOTORES_DC.SchDoc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]
2026-07-11 11 jul 2026
    [1_PAGINA_INICIAL.SchDoc, 2_ALIMENTACAO_24V_5V_3V3.SchDoc, 3_DRV_MOTORES_DE_PASSO.SchDoc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]
2026-07-13 12 jul 2026
    [1_ENTRADA_DE_ALIMENTACAO.SchDoc, 2_MOTORES_DE_PASSO.SchDoc, 3_MOTORES_DC.SchDoc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]
2026-07-15 14 jul 2026
    [4_MICROCONTROLADOR.SchDoc, 5_IO_EXTERNOS.SchDoc, EXPANSION_BOARD.PcbDoc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]
2026-07-16 15 jul 2026
    [1_INTERFACES_EXTERNAS.SchDoc, 1_PFC.SchDoc, 2_FLYBACK_AUXILIAR.SchDoc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]
2026-07-18 17 jul 2026
    [1_INTERFACES_EXTERNAS.SchDoc, 2_MICROCONTROLADOR.SchDoc, 3_TEMP.SchDoc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]
2026-07-18 18 jul 2026
    [2_MICROCONTROLADOR.SchDoc]
2026-07-19 19 jul 2026
    [1_INTERFACES_EXTERNAS.SchDoc, 1_MICROCONTROLADOR.SchDoc, 2_FLYBACK_AUXILIAR.SchDoc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]
2026-07-22 22 jul 2026
    [1_MICROCONTROLADOR.SchDoc, 2_INTERFACES_EXTERNAS.SchDoc, 3_INTERFACE_DOS_DRIVERS.SchDoc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]
2026-07-28 27 jul 2026
    [1_MICROCONTROLADOR.SchDoc, 2_INTERFACES_EXTERNAS.SchDoc, 2_MOTORES_DE_PASSO.SchDoc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]
2026-07-29 29 jul 2026
    [1_MICROCONTROLADOR.SchDoc, 2_INTERFACES_EXTERNAS.SchDoc, 3_INTERFACE_DOS_DRIVERS.SchDoc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]
2026-07-31 31 jul 2026
    [2_INTERFACES_EXTERNAS.SchDoc, 4_MOTORES_DC.SchDoc]
2026-08-02 02 ago 2026
    [1_MICROCONTROLADOR.SchDoc, 1_PFC.SchDoc, 3_INTERFACE_DOS_DRIVERS.SchDoc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]
2026-08-04 04 ago 2026
    [1_MICROCONTROLADOR.SchDoc, 2_INTERFACES_EXTERNAS.SchDoc, 3_INTERFACE_DOS_DRIVERS.SchDoc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]
2026-08-07 07 ago 2026
    [1_ENTRADA_DE_ALIMENTACAO.SchDoc, 1_MICROCONTROLADOR.SchDoc, 2_INTERFACES_EXTERNAS.SchDoc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]
2026-08-09 08 ago 2026
    [1_MICROCONTROLADOR.SchDoc, 4_MOTORES_DC.SchDoc, DRIVER.PrjPcb]
2026-08-09 09 ago 2026
    [DRIVER.PrjPcb]
2026-08-11 10 ago 2026
    [DRIVER.PrjPcb]
2026-08-11 11 ago 2026
    [4_MOTORES_DC.SchDoc, DRIVER.PrjPcb]
2026-08-13 12 ago 2026
    [2_INTERFACES_EXTERNAS.SchDoc, 4_MOTORES_DC.SchDoc, 5_MOTORES_DE_PASSO.SchDoc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]
2026-09-13 13 sep 2026
    [1_PFC.SchDoc, 2_FLYBACK_AUXILIAR.SchDoc, 3_LLC.SchDoc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]
2026-09-17 16 sep 2026
    [3_LLC.SchDoc]
